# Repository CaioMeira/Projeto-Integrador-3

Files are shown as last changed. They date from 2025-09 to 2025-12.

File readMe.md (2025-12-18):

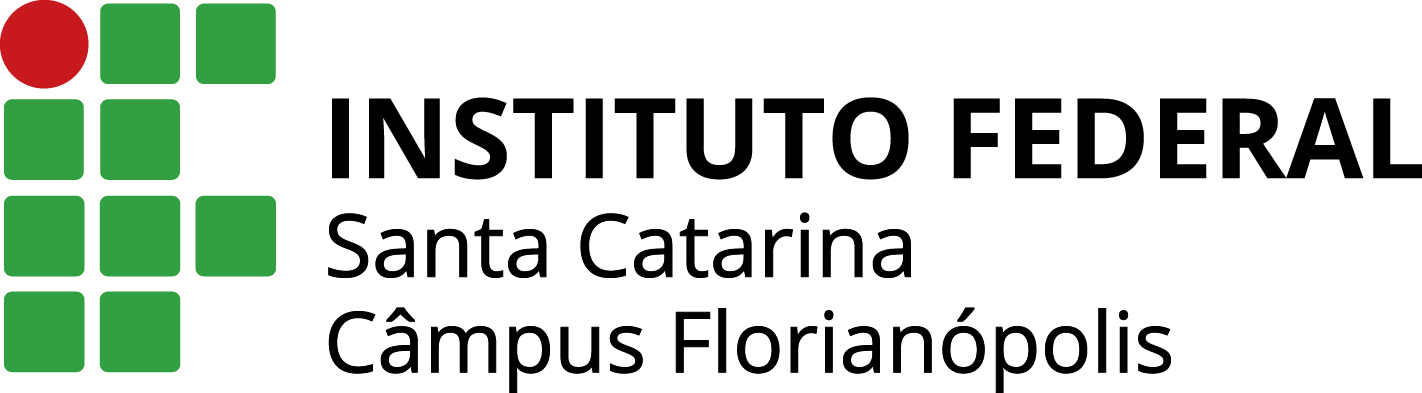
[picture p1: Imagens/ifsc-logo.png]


# Projeto Integrador III - Braço Robótico

## Descrição do Projeto

Repositório destinado ao desenvolvimento do **Projeto Integrador III** do curso de Engenharia Eletrônica.  
O projeto consiste na construção de um **braço robótico controlado por ESP32** integrando o protocolo de comunicação **ROS 2**

---

## Requisitos para Executar o Projeto

### 1. Firmware ESP32 (Obrigatório)

**Arduino IDE** com as seguintes bibliotecas instaladas:

- `ESP32Servo` - Controle de servos
- `EEPROM` (incluída no core ESP32)
- `micro_ros_arduino` v2.0.7-humble - Comunicação ROS 2 (opcional)

**Como instalar:**

```
Arduino IDE → Sketch → Include Library → Manage Libraries
Buscar e instalar cada biblioteca acima
```

### 2. Integração ROS 2 (Opcional - 2 métodos)

#### **Método A: Script Python (Recomendado - Funciona com ESP32 padrão)**

- **Python 3.8+**
- **ROS 2 Humble** (Ubuntu 22.04 ou WSL2)
- **pyserial**: `pip3 install pyserial`

**Vantagens:** Não requer modificação no ESP32, funciona com qualquer modelo

#### **Método B: ROS Nativo via micro-ROS Agent (Docker)**

- **Docker** instalado
- **ROS 2 Humble** (Ubuntu 22.04 ou WSL2)
- **ESP32 com biblioteca micro-ROS** compilada no firmware

**Limitação:** ESP32 padrão (520KB RAM) suporta apenas `/run_macro`. Para todos os tópicos, use ESP32-WROVER ou **Método A (Script Python)**.

### 3. Hardware

- ESP32 DevKit (qualquer modelo)
- 6× Servos MG996R ou similar
- Fonte 5V/6V 3A

---

> ## Equipe
>
> - Caio Neves Meira
> - Guilherme da Costa Franco
> - Marcelo Zampieri Pereira da Silva
>
> Professores: Matheus Leitzke Pinto e Renan Augusto Starke

---

<p align=center><strong>SUMÁRIO</strong></p>

[**1. INTRODUÇÃO**](./introdução.md)<br>
[**2. COMPONENTES**](./componentes.md)<br>
[**3. LISTA DE COMPONENTES**](./lista-de-componentes.md)<br>
[**4. IMAGENS**](./Imagens/)<br>

---

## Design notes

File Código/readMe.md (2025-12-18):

# Braço Robótico ESP32

Este projeto implementa o controle e a automação de um braço robótico de **5 graus de liberdade**, utilizando um **ESP32**.

O foco desta versão foi a **reestruturação modular** e a adoção de uma **arquitetura não-bloqueante baseada em Máquinas de Estado**, garantindo **movimentos suaves (smooth move)** e execução de **rotinas complexas (macros)**.

## Integração ROS 2

Este firmware suporta **integração com ROS 2 Humble** através de duas abordagens:

### Método Recomendado: Bridge Python (`ros2serial_bridge.py`)

- **Funciona com qualquer ESP32** (incluindo modelos padrão sem PSRAM)
- **Todos os tópicos ROS** disponíveis: `/run_macro`, `/run_pose`, `/joint_goals`
- **Setup simples:** `pip install pyserial` + `python3 ros2serial_bridge.py /dev/ttyUSB0`
- **Estabilidade garantida:** Sem limitações de RAM

**Documentação completa:** [IntegraçãoROS.md](./IntegraçãoROS.md)

### Alternativa: micro-ROS Nativo

- Requer ESP32-WROVER (com PSRAM) para todos os tópicos
- ESP32 padrão suporta apenas `/run_macro` (limitação de RAM)
- Latência mais baixa (~10ms vs ~50ms)

**Recomendação:** Use o **Bridge Python** para desenvolvimento e testes. É mais simples e funciona em qualquer hardware!

---

## Arquitetura do Firmware (Modularização)

O código foi dividido em **módulos (namespaces)** com responsabilidades bem definidas, facilitando a leitura, o teste e a expansão.

| **Módulo (Namespace)** | **Responsabilidade Principal** | **Descrição Detalhada** |
| --- | --- | --- |
| **Config** | Constantes e Estruturas | Define pinos, tamanhos de arrays, constantes de velocidade, endereços de EEPROM e structs de dados (`Pose`, `Macro`, `StoredData`). |
| **MotionController** | Movimento dos Servos (Físico)  | Executa o movimento suave (interpolação) dos servos no tempo. Contém variáveis globais de posição, limites e offsets. |
| **Calibration** | Limites e Offsets | Gerencia comandos de `min`, `max`, `offset` e `align` para calibração de software e hardware. |
| **Storage** | Persistência (EEPROM) | Salva e carrega o estado de calibração (min/max/offsets) e a última posição. |
| **PoseManager** | Poses Estáticas | Gerencia criação, listagem, carregamento e exclusão de **Poses** na EEPROM. |
| **MacroManager** | Rotinas Sequenciais | Gerencia criação, listagem, carregamento e exclusão de **Macros** (sequências de poses e tempos). |
| **Sequencer** | Máquina de Estados (Automação) | Executa Macros de forma não-bloqueante, usando `MotionController::isMoving()` para avançar entre passos. |
| **CommandParser** | Interface Serial | Interpreta comandos de texto da Serial (`move`, `set`, `pose save`, `macro play`, etc.) e roteia ao módulo correto. |
| **robotic_arm.ino** | Ponto de Entrada | Inicializa Serial, EEPROM, chama `setup()` dos módulos e mantém o loop principal não-bloqueante. |

---

## Principais Funcionalidades

### 1. Movimento Suave e Não-Bloqueante

**Módulos:** `MotionController` & `robotic_arm.ino`

- **Interpolação (Smooth Move):**  
  O movimento entre A → B é dividido em pequenos passos.  
  O `MotionController::update()` é chamado continuamente no `loop()` principal, calculando ângulos com a função de easing `EaseInOutQuad`.

- **Não-Bloqueante:**  
  O `loop()` principal continua executando outras tarefas (como ler a Serial e atualizar o Sequencer) pois o controle é baseado em `millis()` e não em `delay()`.

#### 1.1 Easing (Interpolação Suave)

Para garantir que o braço **não comece nem pare de forma abrupta** (“engasgos”), utilizamos uma técnica chamada **Easing (abrandamento)**.

Em vez de um movimento **linear** (velocidade constante), o código implementa a equação **EaseInOutQuad**:

$$
\text{easeProgress} =
\begin{cases}
2 \times \text{progress}^2, & \text{se } \text{progress} < 0.5 \\
1 - \dfrac{(-2 \times \text{progress} + 2)^2}{2}, & \text{se } \text{progress} \geq 0.5
\end{cases}
$$

- `progress` → progresso linear (tempo) de `0.0` a `1.0`
- `easeProgress` → progresso ajustado, também de `0.0` a `1.0`

#### 1.2 Efeito da equação

| Etapa | Descrição |
| --- | --- |
| **Início Suave** | O braço começa a se mover lentamente. |
| **Aceleração Central** | A velocidade aumenta gradualmente no meio do trajeto. |
| **Fim Suave** | A velocidade diminui gradualmente ao se aproximar da posição alvo. |

> [!Note]
> Este método de interpolação não apenas torna os movimentos visualmente mais naturais e robóticos, mas também reduz o estresse mecânico e o ruído dos servos.

---

### 2 Módulos de Persistência (EEPROM/Flash)

Para manter o estado do braço robótico, incluindo calibrações, a última posição e as rotinas programadas, o sistema utiliza a memória não-volátil EEPROM (ou a emulação de EEPROM em Flash no caso do ESP32). A memória é organizada em três seções lógicas:

---

#### 2.1. Módulo Storage (Configurações do Sistema)

Este é o módulo base (`Storage.cpp`), responsável por salvar e carregar os dados essenciais para o funcionamento inicial do braço.

**O que Salva:**

- A última posição lógica conhecida de cada servo (`currentAngles`).
- Os limites de software (`minAngles`, `maxAngles`) definidos para segurança.
- Os offsets de calibração (`offsets`) para corrigir desvios mecânicos dos servos.

**Funcionalidade:**  
O módulo utiliza uma chave mágica (`EEPROM_MAGIC`) para garantir que os dados lidos sejam válidos.  
Ao carregar o estado, ele pode opcionalmente iniciar um movimento suave para a última posição salva (como é feito no `setup()` principal).

**Comandos:** `save` e `load`.

---

#### 2.2. Módulo PoseManager (Poses Estáticas)

O `PoseManager` (`PoseManager.cpp`) permite que o usuário defina e armazene posições-chave (poses) na EEPROM para serem reutilizadas.

**Estrutura:**  
As poses são armazenadas em slots de memória fixos (definidos por `MAX_POSES`, atualmente 10), cada uma contendo um nome curto e os ângulos de todos os servos.

**Integração com Movimento:**  
O comando de carregamento de pose (`loadPoseByName`) é diretamente integrado ao `MotionController`, iniciando um movimento suave com a interpolação **EaseInOutQuad** (explicada acima) na duração especificada ou calculada.

**Comandos:**  
`savepose <nome>`, `loadpose <nome> [tempo]`, `listpose` e `delpose <nome>`.

---

#### 2.3. Módulo MacroManager e Sequencer (Rotinas Programadas)

Estes módulos trabalham em conjunto para permitir a criação e execução de sequências complexas de movimento.

**MacroManager:**  
Responsável pela persistência e gestão de **Macros** (`MacroManager.cpp`), que são listas de passos.  
Cada passo (`MacroStep`) armazena o nome de uma Pose e um tempo de espera (`delay_ms`).

**Sequencer:**  
É a **Máquina de Estados (FSM)** que executa a macro de forma não-bloqueante (`Sequencer.cpp`).  
O seu `update()` alterna entre os estados:

- **MOVING:** Enquanto o `MotionController` interpola para a próxima pose.
- **WAITING:** Esperando o `delay_ms` do passo atual antes de avançar.
- **IDLE:** Quando não há macro em execução.

**Comandos:**  
`macro create <nome>`, `macro add <pose> <tempo>`, `macro save <nome>`, `macro play <nome>`, `macro stop`, `macro list` e `macro delete <nome>`.

---

## 3. Tabela de Melhorias (Código Legado vs. Modular)

| **Funcionalidade** | **Código Legado (Monolítico)** | **Versão Modular v5.0** |
| --- | --- | --- |
| **Arquitetura** | Código único (legacy.ino). Configurações, lógica e parsing misturados. | Modular: Namespaces dedicados (MotionController, Storage, etc.) com alto reuso. |
| **Qualidade do Movimento** | Interpolação linear simples, movimentos bruscos. | Interpolação Suave com `EaseInOutQuad`. |
| **Execução de Macros** | Misturado ao parser, sem Máquina de Estados. | Máquina de Estados Não-Bloqueante (`Sequencer`). |
| **Calibração/Persistência** | Misturada à lógica de parsing. | Módulos dedicados `Calibration` e `Storage`. |
| **Comunicação (Parsing)** | `if/else` extensos no `loop()`. | Delegador de Comandos (`CommandParser`). |
| **Manutenção/Escalabilidade** | Baixa: alterações afetam todo o sistema. | Alta: novos recursos exigem apenas 1–2 módulos. |

---

## 4. Comandos de Serial (Resumo)

| **Categoria**  | **Comando** | **Exemplo** | **Descrição** |
| --- | --- | --- | --- |
| **Movimento**  | `move <s0> ... <s6> [tempo]` | `move 90 90 90 90 90 90 90 1000` | Move todos os servos em tempo ms. |
| **Ajuste** | `set <idx> <ang> [tempo]` | `set 3 120 500` | Move o servo 3 para 120° em 500ms. |
| **Poses** | `pose save <nome>` | `pose save HOME` | Salva a posição atual. |
| | `pose load <nome> [tempo]` | `pose load HOME 2000` | Carrega uma pose. |
| **Macros** | `macro create <nome>` | `macro create ROTINA1` | Inicia a criação de uma macro. |
| | `macro add <nome> <pose> <delay>` | `macro add ROTINA1 P1 500` | Adiciona um passo à macro. |
| | `macro play <nome>` | `macro play ROTINA1` | Executa macro de forma não-bloqueante. |
| | `macro stop` | `macro stop` | Interrompe a execução atual. |
| **Calibração** | `offset <idx> <valor>` | `offset 1 -5` | Define offset de calibração. |
| | `min <idx> <ang>` | `min 3 20` | Define o limite mínimo. |
| **Sistema** | `status` | `status` | Exibe posição, limites e offsets. |
| | `save` | `save` | Salva calibração e última posição. |
| | `load` | `load` | Carrega calibração e última posição. |
| | `help` | `help` | Exibe o menu de comandos. |

---

## 5. Integração com ROS 2 (micro-ROS)

O firmware do braço robótico possui um **módulo ROS** (`RosInterface`) que transforma o ESP32 em um **nó ROS 2** nativo, permitindo integração completa com o ecossistema ROS (RViz2, MoveIt2, scripts Python/C++).

### 5.1. Como Funciona

**Arquitetura:**

```
PC (Ubuntu) ←───────────────── USB/Serial ──────────────→ ESP32 (micro-ROS)
    ↓                                                            ↓
Agent (Docker/Script .py)                                 robotic_arm_node
    ↓                                                            ↓
ROS 2 Humble                                           Publishers/Subscribers
```

**Componentes:**

- **ESP32:** Roda o nó `robotic_arm_node` com micro-ROS via Serial (115200 baud)
- **PC:** Executa o micro-ROS Agent (Docker) que faz a ponte Serial ↔ ROS 2
- **Comunicação:** Bidirecional - o braço publica seu estado e recebe comandos

**Integração com Módulos Existentes:**

- `RosInterface` utiliza `MotionController`, `PoseManager` e `Sequencer`
- Todos os comandos Serial continuam funcionando normalmente
- O modo ROS é **não-bloqueante** e coexiste com o parsing Serial

---

### 5.2. Tópicos ROS (Publishers)

O braço **publica** seu estado a **10 Hz**:

| **Tópico** | **Tipo** | **Conteúdo** | **Exemplo de Saída** |
| --- | --- | --- | --- |
| `/joint_states` | `sensor_msgs/JointState` | Posição atual de todas as juntas (em **radianos**) | `position: [1.57, 2.27, 2.27, 1.75, 1.22, 2.09, 1.75]` |
| `/arm_status` | `std_msgs/String` | Estado do braço | `"IDLE"` / `"MOVING"` / `"RUNNING_MACRO"` |

**Monitorar no terminal:**

```bash
# Ver estado das juntas em tempo real
ros2 topic echo /joint_states

# Ver status do braço
ros2 topic echo /arm_status
```

**Conversão:** Os ângulos são publicados em **radianos** (padrão ROS):

- 0° = 0 rad | 90° = 1.57 rad | 180° = 3.14 rad

---

### 5.3. Tópicos ROS (Subscribers)

O braço **escuta** comandos via 3 tópicos:

| **Tópico** | **Tipo** | **Descrição** | **Exemplo de Uso** |
| --- | --- | --- | --- |
| `/joint_goals` | `sensor_msgs/JointState` | Comandar ângulos específicos (radianos) | Mover servo 0 para 90° (1.57 rad) |
| `/run_pose` | `std_msgs/String` | Executar pose salva pelo nome | Carregar pose `"HOME"` |
| `/run_macro` | `std_msgs/String` | Executar macro pelo nome | Executar sequência `"ROTINA1"` |

#### Exemplos de Comandos:

**1. Mover todos os servos para 90°:**

```bash
ros2 topic pub /joint_goals sensor_msgs/msg/JointState "{
  name: ['junta_base', 'junta_ombro1', 'junta_ombro2', 'junta_cotovelo', 'junta_mao', 'junta_pulso', 'junta_garra'],
  position: [1.57, 1.57, 1.57, 1.57, 1.57, 1.57, 1.57]
}" --once
```

**2. Executar pose salva:**

```bash
ros2 topic pub /run_pose std_msgs/msg/String "data: 'HOME'" --once
```

**3. Executar macro:**

```bash
ros2 topic pub /run_macro std_msgs/msg/String "data: 'ROTINA1'" --once
```

---

### 5.4. Configuração Rápida

#### Passo 1: Compilar e Enviar o Firmware

1. Instale a biblioteca `micro_ros_arduino` no Arduino IDE
2. Compile e envie o código para o ESP32
3. O ESP32 aguardará a conexão do Agent

#### Passo 2: Rodar o Agent no PC

```bash
# Identificar porta USB (geralmente /dev/ttyUSB0 ou /dev/ttyACM0)
dmesg | grep tty

# Executar Agent via Docker
docker run -it --rm --privileged \
    -v /dev:/dev \
    microros/micro-ros-agent:humble \
    serial --dev /dev/ttyUSB0 -b 115200
```

**Saída Esperada:**

```
[INFO] Serial device: /dev/ttyUSB0, baudrate: 115200
[INFO] session established
```

#### Passo 3: Verificar Conexão

```bash
# Listar tópicos disponíveis
ros2 topic list

# Deve aparecer:
# /arm_status
# /joint_goals
# /joint_states
# /run_macro
# /run_pose
```

---

### 5.5. Saídas Esperadas e Diagnóstico

**Conexão Bem-Sucedida:**

**No Serial Monitor do ESP32:**

```
Iniciando RosInterface (modo SERIAL)...
Transporte micro-ROS: Serial (USB)
micro-ROS (Serial) configurado e pronto.
```

**No terminal do Agent:**

```
[1669123457.123] session established
[1669123457.124] Root.cpp init_session
```

**Testando comunicação:**

```bash
# Publicar estado deve atualizar em tempo real
ros2 topic hz /joint_states
# Saída: average rate: 10.000

# Status deve responder ao movimento
ros2 topic echo /arm_status
# "IDLE" quando parado, "MOVING" durante movimento
```

---

**Problemas Comuns:**

| **Sintoma** | **Causa Provável** | **Solução** |
| --- | --- | --- |
| Agent não conecta | Permissões USB | `sudo usermod -aG dialout $USER` e fazer logout/login  |
| Tópicos não aparecem | Agent não está rodando | Verificar `docker ps` |
| ESP32 reseta sozinho | Watchdog timeout | Verificar se `RosInterface::update()` está no `loop()` |
| Erro "X posições recebidas" | Número incorreto de juntas | Sempre enviar 7 valores em `/joint_goals` |

---

**Documentação Completa:**  
Para detalhes avançados, troubleshooting e exemplos de integração com MoveIt2/RViz2, consulte o arquivo [`IntegraçãoROS.md`](./IntegraçãoROS.md).

---

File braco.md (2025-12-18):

# Impressão 3D do Braço Robótico

Este projeto iniciou-se com a utilização de um **braço robótico parcialmente montado**, que desde as primeiras etapas apresentou **limitações estruturais e funcionais relevantes**. O modelo inicial possuía **5 graus de liberdade (DOF)** e era acionado por **7 servomotores**.

Com o avanço do desenvolvimento do código e a realização de testes experimentais, constatou-se que essas limitações físicas **comprometiam a confiabilidade do sistema**, além de dificultarem a evolução segura e consistente do projeto.

Diante desse cenário — e considerando a **experiência limitada da equipe no desenvolvimento e modelagem de componentes 3D** — optou-se pela **substituição do braço original** por um modelo já consolidado e amplamente utilizado em projetos públicos.

O novo braço robótico selecionado também possui **5 DOF**, porém utiliza **6 servomotores**, apresentando uma **arquitetura mecânica mais simples, robusta e confiável**, alinhada aos requisitos técnicos e aos objetivos do projeto.

A partir dos arquivos `.stl` disponibilizados pelo projeto escolhido, todas as peças foram impressas utilizando as **quatro impressoras 3D disponíveis no laboratório LPAE** e o software UltiMaker Cura, resultando em uma estrutura física **mais estável, precisa e adequada** para a continuidade do projeto.

---

## Visualização dos Modelos

Os modelos 3D utilizados na construção do novo braço robótico estão disponíveis no formato `.stl` e podem ser acessados diretamente no diretório abaixo:

**Diretório dos modelos 3D**  
https://github.com/CaioMeira/Projeto-Integrador-3/tree/main/Imagens/3D

---

##  Componentes do Braço Robótico

O novo braço robótico é composto por **10 modelos distintos**, totalizando a impressão de **14 peças**, conforme descrito na tabela a seguir:

| Arquivo `.stl` | Quantidade | Função |
|---|:---:|---|
| `Arm01.stl` | 1 | Segmento principal do braço |
| `Arm 02 v3.stl` | 1 | Segundo segmento articulado |
| `Arm 03.stl` | 1 | Terceiro segmento do braço |
| `Base.stl` | 1 | Base estrutural do braço robótico |
| `Waist.stl` | 1 | Estrutura de rotação do eixo principal |
| `gear1.stl` | 1 | Engrenagem garra |
| `gear2.stl` | 1 | Engrenagem garra |
| `Gripper base.stl` | 1 | Base do mecanismo da garra |
| `Gripper 1.stl` | 2 | Garras de preensão |
| `grip link 1.stl`  | 4 | Elos do mecanismo da garra |

**Total de peças impressas:** **14 unidades**

 O conjunto dessas peças resulta em um **braço robótico completo, funcional e mecanicamente estável**.

---

##  Tecnologias Utilizadas

- Impressão 3D (arquivos `.stl`)
- Servomotores
- Modelos mecânicos open-source
- Infraestrutura do laboratório **LPAE**

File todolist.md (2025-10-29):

### Próximos passos a serem executados no projeto.

- [ ] Corrigir conexão mecânica entre servomotor 1 e servomotor 3

- [X] Desenvolver sistema de alimentação para prover o necessário de energia para um uso síncrono dos servomotores
  
- [ ] Devido Cable Management para evitar problemas durante o movimento

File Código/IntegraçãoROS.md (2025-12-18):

# Guia de Integração micro-ROS com ESP32

**Versão:** 1.0  
**ROS 2:** Humble  
**Plataforma:** ESP32 + Ubuntu 22.04  
**Protocolo:** Serial (USB)

---

## Índice

1. [Visão Geral](#visão-geral)
2. [Arquitetura](#arquitetura)
3. [Configuração do ESP32](#passo-1-configuração-do-esp32)
4. [Agente micro-ROS no PC](#passo-2-agente-micro-ros-no-pc)
5. [Testando a Comunicação](#passo-3-testando-a-comunicação)
6. [Comandos Disponíveis](#comandos-ros-disponíveis)
7. [Troubleshooting](#troubleshooting)

---

## Visão Geral

Seu braço robótico agora é um **nó ROS 2** (`robotic_arm_node`) que:

- **Publica** estado das juntas e status do braço (10 Hz)
- **Recebe** comandos de movimento, poses e macros via ROS
- Comunica via **Serial (USB)** com micro-ROS Agent no PC
- Compatível com **ROS 2 Humble** (Ubuntu 22.04)

### Por que usar micro-ROS?

- Integração nativa com ecossistema ROS 2
- Visualização no RViz2 (com URDF do braço)
- Compatibilidade com MoveIt2 para planejamento de trajetórias
- Scripts Python/C++ para automação complexa

---

## Arquitetura

```
┌─────────────────────────────────────────────────────────────┐
│                       PC Linux (Ubuntu 22.04)               │
│  ┌──────────────────────────────────────────────────────┐   │
│  │  micro-ROS Agent (Docker)                            │   │
│  │  - Porta: /dev/ttyUSB0 (Serial)                      │   │
│  │  - Baudrate: 115200                                  │   │
│  └─────────────────┬────────────────────────────────────┘   │
│                    │ USB                                    │
│  ┌─────────────────┴────────────────────────────────────┐   │
│  │  ROS 2 Humble                                        │   │
│  │  - ros2 topic list/echo/pub                          │   │
│  │  - RViz2, MoveIt2, etc                               │   │
│  └──────────────────────────────────────────────────────┘   │
└─────────────────────────────────────────────────────────────┘
                          ▲
                          │ Serial (115200 baud)
                          ▼
┌─────────────────────────────────────────────────────────────┐
│                       ESP32 (Braço Robótico)                │
│  ┌──────────────────────────────────────────────────────┐   │
│  │  robotic_arm_node (micro-ROS)                        │   │
│  │                                                      │   │
│  │  Publishers (10 Hz):                                 │   │
│  │    - /joint_states → Ângulos atuais (radianos)       │   │
│  │    - /arm_status → IDLE / MOVING / RUNNING_MACRO     │   │
│  │                                                      │   │
│  │  Subscribers:                                        │   │
│  │    - /joint_goals ← Comandar ângulos (radianos)      │   │
│  │    - /run_pose ← Executar pose salva                 │   │
│  │    - /run_macro ← Executar macro (sequência)         │   │
│  └──────────────────────────────────────────────────────┘   │
│  ┌──────────────────────────────────────────────────────┐   │
│  │  MotionController + PoseManager + Sequencer          │   │
│  │  (Código otimizado Fases 1 e 2)                      │   │
│  └──────────────────────────────────────────────────────┘   │
└─────────────────────────────────────────────────────────────┘
```

### Fluxo de Comunicação

1. **ESP32** aguarda conexão do Agent via Serial
2. **PC** executa micro-ROS Agent (Docker) conectado à porta USB
3. **Agent** estabelece comunicação bidirecional
4. **ROS 2** vê o ESP32 como um nó normal (`robotic_arm_node`)
5. Você pode usar `ros2 topic pub/echo` normalmente!

---

## Passo 1: Configuração do ESP32

### 1.1 Instalar Biblioteca micro-ROS

**Arduino IDE:**

```
Sketch → Include Library → Manage Libraries
Buscar: "micro_ros_arduino"
Instalar versão compatível com ROS 2 Humble
```

**PlatformIO:**

```ini
[env:esp32]
platform = espressif32
board = esp32dev
framework = arduino
lib_deps =
    https://github.com/micro-ROS/micro_ros_arduino/releases/download/v2.0.7/micro_ros_arduino-2.0.7.zip
```

### 1.2 Compilar e Enviar

1. Abra o projeto em `Código/robotic_arm/`
2. Compile e envie para o ESP32
3. Abra o **Monitor Serial** (115200 baud)

### 1.3 Verificar Inicialização

Você deve ver:

```
Iniciando Sistema do Braco Robotico v5.0...
Watchdog Timer configurado (15s).
...
Iniciando RosInterface (modo SERIAL)...
Transporte micro-ROS: Serial (USB)
micro-ROS (Serial) configurado e pronto.
```

> **Atenção:** O ESP32 ficará **esperando** o Agent se conectar. Isso é normal!

---

## Passo 2: Agente micro-ROS no PC

### 2.1 Identificar a Porta Serial

Conecte o ESP32 ao PC via USB e execute:

```bash
dmesg | grep tty
```

**Saída esperada:**

```
[12345.678] usb 1-1: FTDI USB Serial Device converter now attached to ttyUSB0
```

A porta é `/dev/ttyUSB0` (ou `ttyACM0`, depende do ESP32).

### 2.2 Rodar o Agent (Docker)

**Método 1: Acesso privilegiado (mais simples)**

```bash
docker run -it --rm --privileged \
    -v /dev:/dev \
    microros/micro-ros-agent:humble \
    serial --dev /dev/ttyUSB0 -b 115200
```

**Método 2: Mapear dispositivo específico (mais seguro)**

```bash
docker run -it --rm \
    --device=/dev/ttyUSB0:/dev/ttyUSB0 \
    microros/micro-ros-agent:humble \
    serial --dev /dev/ttyUSB0 -b 115200
```

### 2.3 Verificar Conexão

**Saída esperada no Agent:**

```
[1669123456.789] micro-ROS Agent
[1669123456.790] Version: 2.0.0
[1669123456.791] Serial device: /dev/ttyUSB0, baudrate: 115200
[1669123457.123] session established
[1669123457.124] Root.cpp init_session
```

> **Sucesso!** O ESP32 agora está conectado ao ROS 2.

---

## Passo 3: Testando a Comunicação

** IMPORTANTE:** Mantenha o terminal do Agent **rodando** durante todos os testes!

### 3.1 Listar Tópicos Disponíveis

Abra um **novo terminal** e execute:

```bash
ros2 topic list
```

**Saída esperada:**

```
/arm_status
/joint_goals
/joint_states
/parameter_events
/rosout
/run_macro
/run_pose
```

> Se você vê `/joint_states` e `/arm_status`, está funcionando!

---

### 3.2 Monitorar o Estado do Braço (Publishers)

#### Ver Estado das Juntas (10 Hz)

```bash
ros2 topic echo /joint_states
```

**Saída (exemplo):**

```yaml
header:
  stamp:
    sec: 1234567890
    nanosec: 123456789
  frame_id: ""
name:
  - junta_base
  - junta_ombro1
  - junta_ombro2
  - junta_cotovelo
  - junta_mao
  - junta_pulso
  - junta_garra
position:
  - 1.5707963 # 90° em radianos
  - 2.2689280 # 130° em radianos
  - 2.2689280 # 130° em radianos
  - 1.7453292 # 100° em radianos
  - 1.2217304 # 70° em radianos
  - 2.0943951 # 120° em radianos
  - 1.7453292 # 100° em radianos
velocity: []
effort: []
```

> **Dica:** Para converter radianos → graus: `graus = radianos × 180 / π`

#### Ver Status do Braço

```bash
ros2 topic echo /arm_status
```

**Saída:**

```yaml
data: "IDLE"
```

Possíveis valores:

- `IDLE` - Braço parado
- `MOVING` - Executando movimento suave
- `RUNNING_MACRO` - Executando sequência de macro

---

### 3.3 Comandar o Braço (Subscribers)

#### Comando 1: Executar Pose Salva

> **Pré-requisito:** Você deve ter uma pose salva (via Serial: `SAVE home`).

```bash
ros2 topic pub /run_pose std_msgs/msg/String "data: 'home'" --once
```

O braço deve se mover para a pose `home`.

---

#### Comando 2: Comandar Ângulos Específicos

Mover todos os servos para **90 graus** (1.5708 radianos):

```bash
ros2 topic pub /joint_goals sensor_msgs/msg/JointState "{
  name: ['junta_base', 'junta_ombro1', 'junta_ombro2', 'junta_cotovelo', 'junta_mao', 'junta_pulso', 'junta_garra'],
  position: [1.57, 1.57, 1.57, 1.57, 1.57, 1.57, 1.57]
}" --once
```

**Conversão rápida:**

- 0° = 0 rad
- 45° = 0.785 rad
- 90° = 1.57 rad
- 135° = 2.356 rad
- 180° = 3.14 rad

---

#### Comando 3: Executar Macro

**Pré-requisito:** Você deve ter uma macro salva (via Serial).

**Exemplo de criação de macro via Serial:**

```
RECORD pegar
MOVE 0 45
WAIT 1000
MOVE 1 90
END
```

**Executar via ROS:**

```bash
ros2 topic pub /run_macro std_msgs/msg/String "data: 'pegar'" --once
```

O braço executa toda a sequência automaticamente.

---

## Comandos ROS Disponíveis

### Subscribers (Enviar Comandos)

| Tópico | Tipo | Descrição | Exemplo |
| --- | --- | --- | --- |
| `/joint_goals` | `sensor_msgs/JointState` | Comandar ângulos em **radianos** | Ver [Comando 2](#comando-2-comandar-ângulos-específicos) |
| `/run_pose` | `std_msgs/String` | Executar pose salva pelo nome | `data: 'home'` |
| `/run_macro` | `std_msgs/String` | Executar macro pelo nome | `data: 'pegar'` |

### Publishers (Receber Feedback)

| Tópico | Tipo | Frequência | Descrição |
| --- | --- | --- | --- |
| `/joint_states` | `sensor_msgs/JointState` | 10 Hz | Posição atual de todas as juntas |
| `/arm_status` | `std_msgs/String` | 10 Hz | Status: `IDLE`, `MOVING`, `RUNNING_MACRO` |

---

---

## ✅ Alternativa: Bridge Python (Recomendado)

### Por que usar o Script Python?

**Devido a limitações de memória do ESP32 padrão (520KB RAM)**, a integração micro-ROS nativa suporta apenas o tópico `/run_macro`. Para habilitar **todos os tópicos ROS** sem modificar hardware:

✅ **Use o script `ros2serial_bridge.py`** - Funciona com qualquer ESP32!

Este script atua como um **tradutor** entre ROS 2 e comandos seriais do ESP32, eliminando a necessidade de processar ROS diretamente no microcontrolador.

### Arquitetura do Bridge

```
┌──────────────────────────────────────────┐
│       PC Linux (ROS 2 Humble)            │
│                                          │
│  ┌────────────────────────────────────┐  │
│  │  ros2serial_bridge.py              │  │
│  │  • Subscribers: /run_macro,        │  │
│  │    /run_pose, /joint_goals         │  │
│  │  • Publishers: /joint_states,      │  │
│  │    /arm_status                     │  │
│  │  • Conversão: ROS ↔ Serial         │  │
│  └────────────┬───────────────────────┘  │
│               │ Serial (pyserial)        │
└───────────────┼──────────────────────────┘
                │ USB
                ▼
┌──────────────────────────────────────────┐
│       ESP32 (Firmware Padrão)            │
│  • Recebe comandos via Serial            │
│  • Executa movimentos                    │
│  • Responde status                       │
└──────────────────────────────────────────┘
```

### Instalação do Bridge Python

#### 1. Instalar Dependências

```bash
# ROS 2 Humble (se ainda não tiver)
sudo apt install ros-humble-desktop

# pyserial
pip3 install pyserial
```

#### 2. Verificar Porta Serial

```bash
# Conecte o ESP32 via USB
ls /dev/ttyUSB*
# ou
ls /dev/ttyACM*
```

#### 3. Dar Permissões de Acesso

```bash
sudo usermod -aG dialout $USER
# Fazer logout e login novamente
```

### Uso do Bridge Python

#### Iniciar o Bridge

```bash
# Source ROS 2
source /opt/ros/humble/setup.bash

# Executar bridge (substitua /dev/ttyUSB0 pela sua porta)
python3 ros2serial_bridge.py /dev/ttyUSB0
```

**Saída esperada:**

```
[INFO] [robotic_arm_bridge]: Conectando a /dev/ttyUSB0 @ 115200...
[INFO] [robotic_arm_bridge]: Conexão serial estabelecida!
[INFO] [robotic_arm_bridge]: Bridge ROS 2 ↔ Serial inicializado!
[INFO] [robotic_arm_bridge]: Tópicos ativos:
[INFO] [robotic_arm_bridge]:   SUB: /run_macro, /run_pose, /joint_goals
[INFO] [robotic_arm_bridge]:   PUB: /joint_states, /arm_status
```

---

### Testando com o Bridge Python

#### Listar Tópicos

```bash
# Abra um NOVO terminal
source /opt/ros/humble/setup.bash
ros2 topic list
```

**Saída esperada:**

```
/arm_status       ✅
/joint_goals      ✅ (via bridge)
/joint_states     ✅
/run_macro        ✅ (via bridge)
/run_pose         ✅ (via bridge)
```

#### Comandar Ângulos Específicos

```bash
ros2 topic pub /joint_goals sensor_msgs/msg/JointState "{
  name: ['base','ombro1','ombro2','cotovelo','mao','pulso','garra'],
  position: [1.57, 1.57, 1.57, 1.57, 1.57, 1.57, 1.57]
}" --once
```

**O que acontece:**

1. Bridge recebe mensagem ROS em `/joint_goals`
2. Converte radianos → graus: `[90, 90, 90, 90, 90, 90, 90]`
3. Envia comando serial: `move 90 90 90 90 90 90 90`
4. ESP32 executa movimento
5. Bridge publica feedback em `/arm_status`: `MOVING` → `IDLE`

#### Executar Pose

```bash
ros2 topic pub /run_pose std_msgs/msg/String "data: 'pose1'" --once
```

**Tradução pelo bridge:** `pose load pose1`

#### Executar Macro

```bash
ros2 topic pub /run_macro std_msgs/msg/String "data: 'ida'" --once
```

**Tradução pelo bridge:** `macro play ida`

---

### Comparação: Bridge Python vs micro-ROS Nativo

| Aspecto | Bridge Python | micro-ROS Nativo |
| --- | --- | --- |
| **Requisitos ESP32** | Firmware padrão | micro-ROS compilado |
| **RAM necessária** | Qualquer modelo | ESP32-WROVER (PSRAM) |
| **Tópicos suportados** | ✅ Todos (3 subs + 2 pubs) | ⚠️ Apenas /run_macro (ESP32 padrão) |
| **Instalação** | `pip install pyserial` | Docker + Agent |
| **Latência** | ~50-100ms | ~10-20ms |
| **Complexidade** | 🟢 Baixa | 🔴 Alta |
| **Estabilidade** | ✅ Alta | ⚠️ Reset loops (ESP32 padrão) |
| **Recomendado para** | Desenvolvimento/Produção | Sistemas com PSRAM |

### Quando Usar Cada Método?

#### Use o **Bridge Python** se:

- ✅ Você tem ESP32 **padrão** (sem PSRAM)
- ✅ Quer **todos os tópicos** ROS funcionando
- ✅ Prefere **simplicidade** de setup
- ✅ Latência de ~50ms é aceitável
- ✅ Está em fase de **desenvolvimento/testes**

#### Use o **micro-ROS Nativo** se:

- ⚠️ Você tem ESP32-**WROVER** (com PSRAM)
- ⚠️ Precisa de **latência mínima** (<20ms)
- ⚠️ Quer eliminar o PC intermediário
- ⚠️ Está disposto a lidar com **limitações de RAM**

---

## Troubleshooting

### Problema 1: Agent não conecta (micro-ROS Nativo)

**Sintomas:**

```
[ERROR] Cannot open serial device /dev/ttyUSB0
```

**Solução:**

```bash
# Verificar permissões
ls -l /dev/ttyUSB0

# Adicionar seu usuário ao grupo dialout
sudo usermod -aG dialout $USER

# Fazer logout e login novamente
```

---

### Problema 2: ESP32 não aparece no `ros2 topic list`

**Verificar:**

1. Agent está rodando? (Docker container ativo?)
2. ESP32 mostra "session established" no Serial Monitor?
3. Baudrate correto? (115200 em ambos os lados)

**Teste:**

```bash
# Reiniciar ESP32
# Pressione o botão RST no ESP32

# Verificar Agent
docker ps  # Container deve estar UP
```

---

### Problema 3: "ERRO ROS: /joint_goals recebido com X posições"

**Causa:** Você enviou número incorreto de ângulos.

**Solução:** Sempre envie **7 posições** (uma para cada servo):

```bash
ros2 topic pub /joint_goals sensor_msgs/msg/JointState "{
  name: ['j0','j1','j2','j3','j4','j5','j6'],
  position: [1.57, 1.57, 1.57, 1.57, 1.57, 1.57, 1.57]
}" --once
```

---

### Problema 4: Watchdog reseta o ESP32

**Causa:** Loop principal travou por >15 segundos.

**Verificar:**

- Nenhum `delay()` longo no código
- `RosInterface::update()` está sendo chamado no `loop()`
- Nenhuma operação bloqueante

---

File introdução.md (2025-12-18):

# Projeto Integrador III - Braço Robótico

## Problema  
O Brasil ainda enfrenta grandes desafios relacionados ao desenvolvimento tecnológico e industrial.  
Apesar de possuir abundância de matéria-prima, grande parte dela é exportada para países que, por sua vez, a transformam em produtos de alto valor agregado e posteriormente os revendem ao mercado brasileiro.  

Esse ciclo resulta em uma dependência tecnológica significativa, altos custos para aquisição de equipamentos e máquinas industriais, além de reduzir a competitividade das indústrias nacionais.  

Nesse contexto, a automação e a robótica se apresentam como ferramentas fundamentais para fomentar o crescimento da indústria local. No entanto, a aquisição de sistemas robóticos modernos, como braços manipuladores industriais, ainda é extremamente onerosa para micro e pequenos empreendedores. Esse fator cria uma barreira de entrada para empresas emergentes que poderiam utilizar tais tecnologias para expandir suas capacidades produtivas e explorar novos mercados.  

O desenvolvimento de um protótipo de braço robótico de baixo custo, utilizando plataformas acessíveis de hardware e software livre, como ESP32 e ROS (Robot Operating System), pode contribuir de forma significativa para reduzir esse obstáculo.  
Tal solução poderia permitir que pequenos negócios implementem processos automatizados de forma mais barata, escalável e eficiente, fortalecendo a indústria nacional e, ao mesmo tempo, diminuindo a dependência externa de equipamentos de alto custo.  

---

## Motivação  
O presente projeto tem sua origem no Projeto Integrador II, no qual já foram trabalhados conceitos relacionados à automação de processos utilizando microcontroladores, sensores e atuadores. Durante essa etapa, foi possível identificar o potencial da automação na solução de problemas práticos e no aumento da eficiência de sistemas.  

Com base nessa experiência, no Projeto Integrador III, buscou-se unir os conceitos de automação com a área de robótica, resultando no desenvolvimento de um protótipo de braço robótico articulado com 5 DoF.  
Essa evolução foi motivada pela necessidade de aprofundar os conhecimentos adquiridos e explorar uma área estratégica para o futuro da indústria 4.0, permitindo também uma aplicação mais direta em problemas reais de manufatura e logística.  

Além disso, a escolha pela integração com o ROS e o simulador Gazebo foi motivada pela possibilidade de aproximar o projeto dos padrões utilizados em centros de pesquisa e indústrias avançadas, garantindo que o aprendizado e os resultados obtidos sejam compatíveis com o estado da arte em robótica.  

Dessa forma, o projeto não apenas consolida os conhecimentos adquiridos ao longo do curso, mas também busca gerar impacto social e econômico, tornando a tecnologia mais acessível e fortalecendo a competitividade das pequenas indústrias brasileiras.  

---

## Objetivo Geral  
Desenvolver um braço robótico de baixo custo, controlado por ESP32, integrado ao sistema ROS e ao simulador Gazebo, de forma a oferecer uma solução acessível para fins educacionais, experimentais e de apoio a micro e pequenos empreendedores.  

---

## Objetivos Específicos  
1. Projetar a arquitetura de hardware e software do braço robótico utilizando ESP32, driver PCA9685 e servomotores.  
2. Implementar a comunicação entre o ESP32 e o ROS via rede sem fio (Wi-Fi/Bluetooth).  
3. Desenvolver algoritmos de controle para movimentação dos graus de liberdade do braço robótico.  
4. Simular o funcionamento do protótipo no ambiente Gazebo, garantindo validação prévia antes da implementação física.  
5. Realizar a integração prática do sistema físico com o ROS, validando a correspondência entre o protótipo e o modelo simulado.  
6. Oferecer uma alternativa de baixo custo que possibilite a aplicação do braço robótico em contextos educacionais e em pequenas linhas de produção.

## Diagrama de blocos

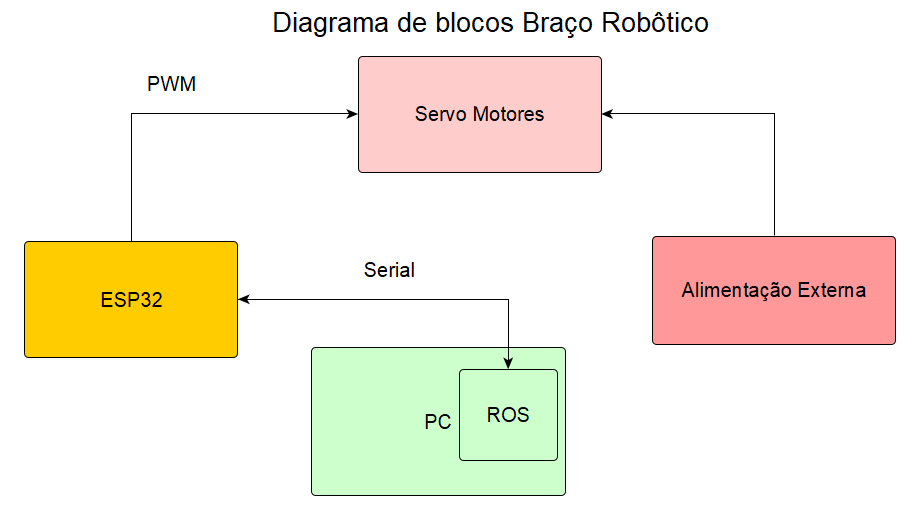
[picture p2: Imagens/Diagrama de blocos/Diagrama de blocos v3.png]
Diagrama_de_blocos_v1


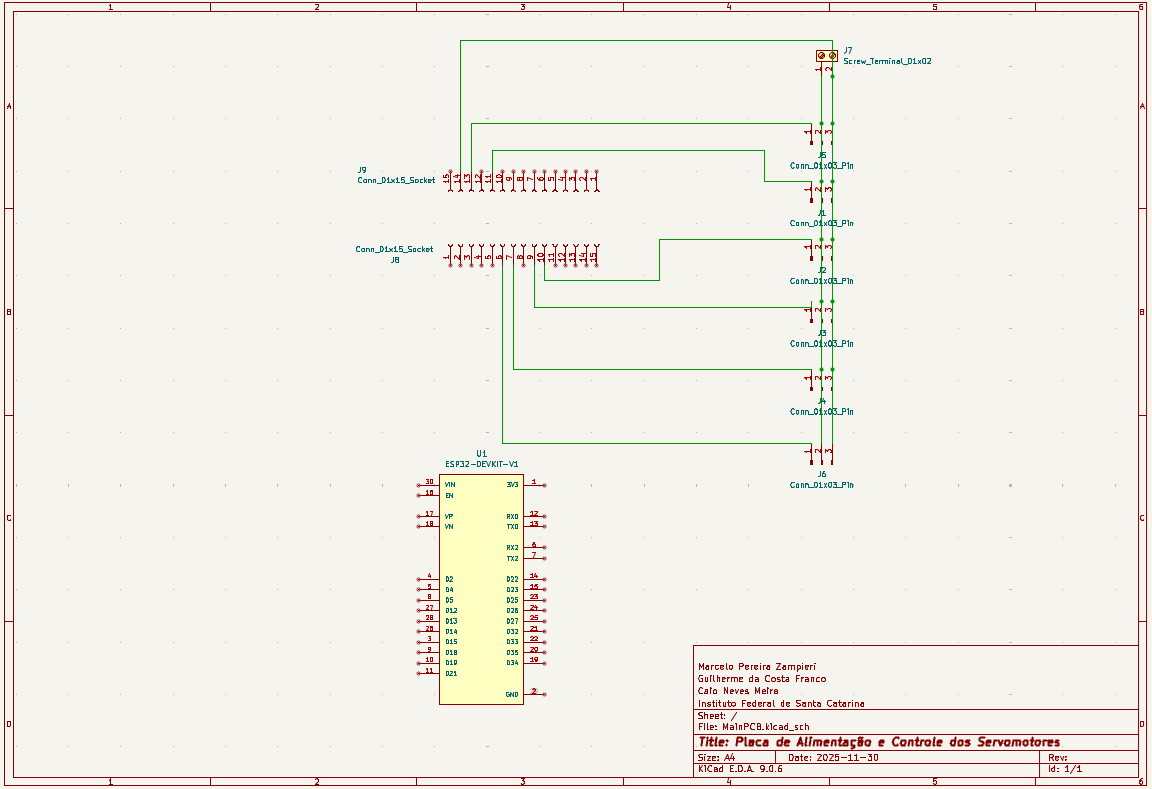
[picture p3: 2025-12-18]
PCI/Esquematico_PCI.png

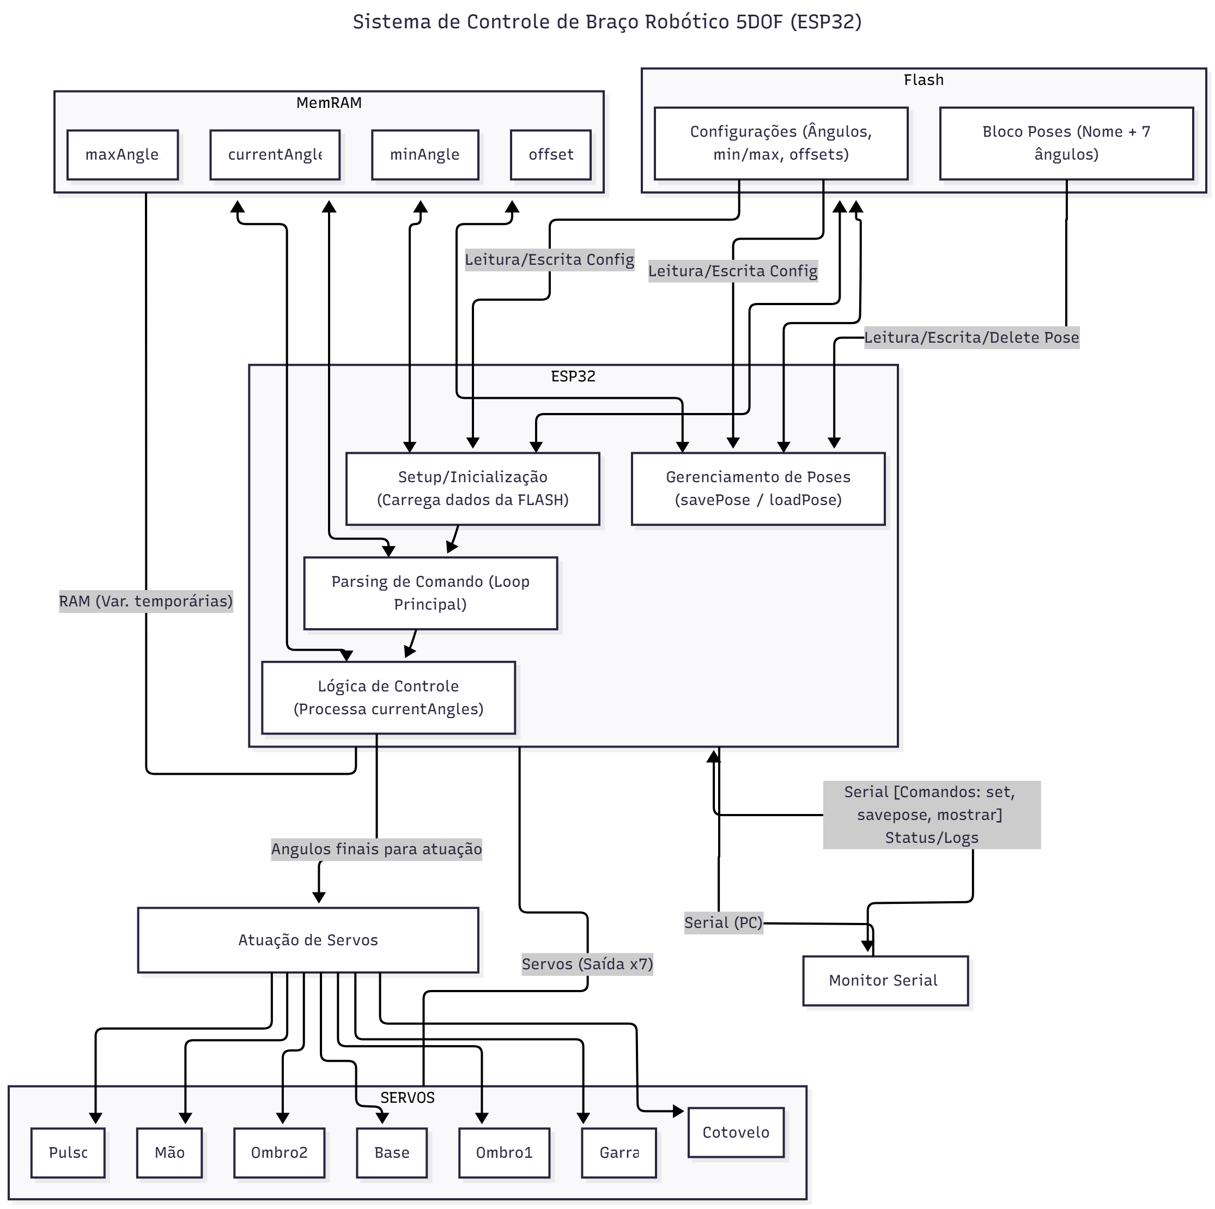
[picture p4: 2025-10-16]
Imagens/Diagrama de blocos/Diagrama de blocos 1ºcod.png

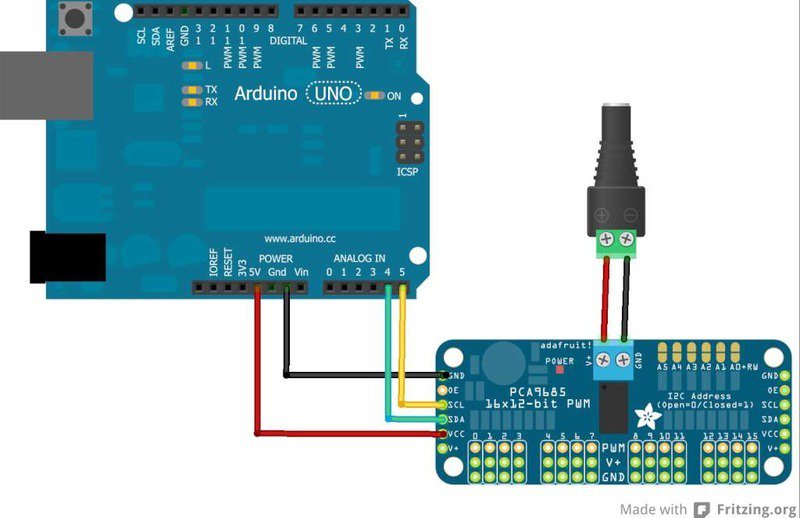
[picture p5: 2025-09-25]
Imagens/PCA9685/modulo-circuito1.jpg

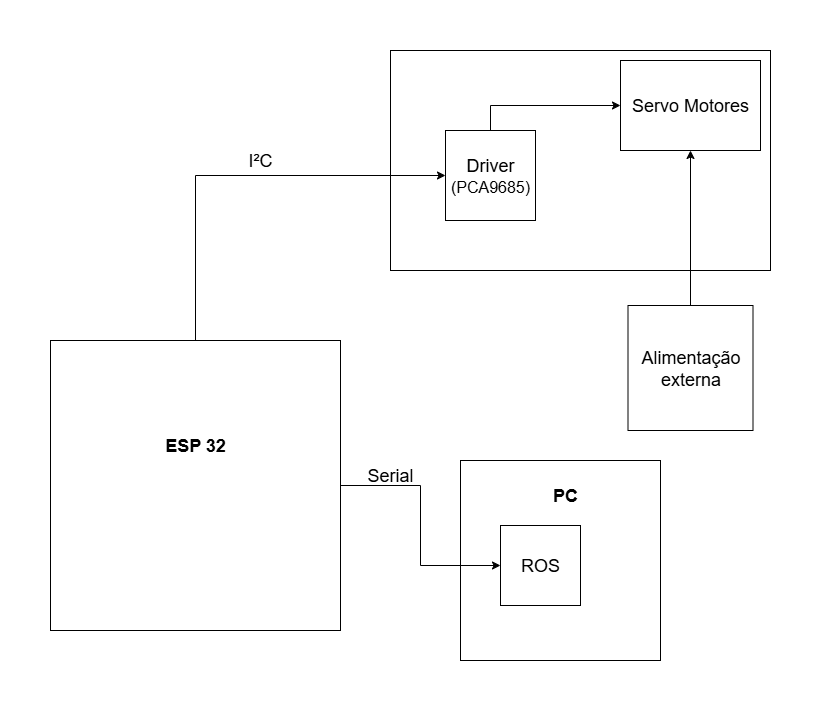
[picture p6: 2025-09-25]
Imagens/Diagrama de blocos/Diagrama de blocos v2.png

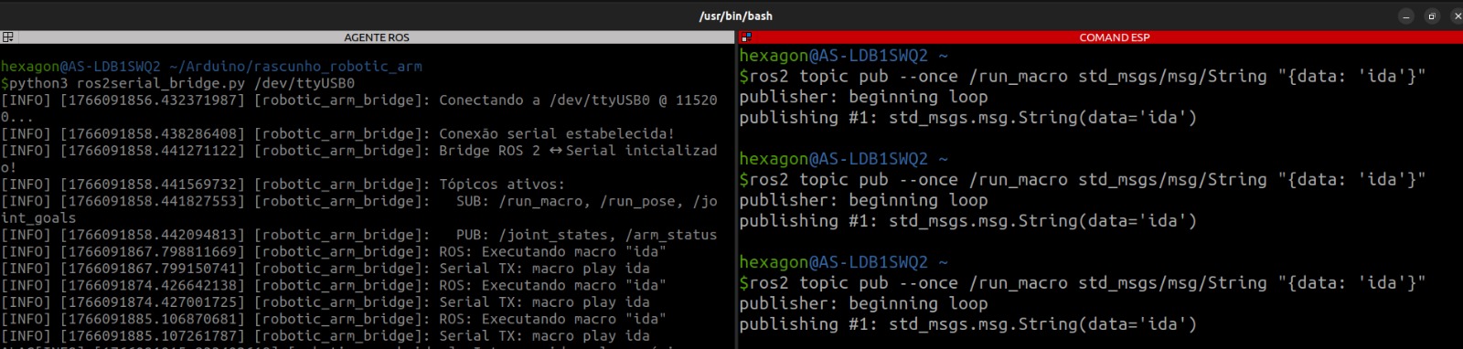
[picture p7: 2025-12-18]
Imagens/UserView/userview.jpg

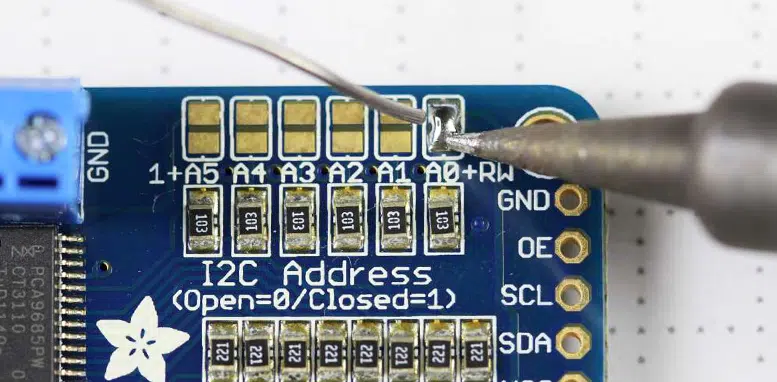
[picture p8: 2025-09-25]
Imagens/PCA9685/adafruit_products_2012_10_13_IMG_0692-1024.png.webp

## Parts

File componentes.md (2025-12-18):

# Componentes e Justificativas Técnicas

## 1. Microcontrolador ESP32 e Mapeamento dos Servomotores

### Por que escolher o ESP32 para controle de braço robótico

O ESP32 é uma excelente escolha para sistemas embarcados em robótica, especialmente para braços robóticos com múltiplos graus de liberdade. Ele oferece:

- **Conectividade integrada (Wi-Fi + Bluetooth)**  
  Ideal para controle remoto, integração com ROS via rede local, atualizações OTA e comunicação com interfaces web ou móveis.

- **Alto desempenho computacional**  
  Processador dual-core com clock de até 240 MHz, suporte a multitarefa via FreeRTOS, e memória suficiente para controle de servos, leitura de sensores e comunicação com ROS.

- **Recursos periféricos robustos**  
  GPIOs abundantes, suporte a PWM, ADCs, SPI, I²C, UARTs, permitindo controle direto de servos, leitura de sensores analógicos/digitais e comunicação com periféricos externos.

- **Ecossistema maduro e flexível**  
  Compatível com Arduino IDE, PlatformIO e ESP-IDF. Possui ampla documentação, bibliotecas e comunidade ativa — facilitando prototipagem, debugging e integração com ROS/micro-ROS.

### Recomendações de integração com servomotores

- Utilizar o ESP32 para controle lógico, leitura de sensores e comunicação com ROS.
- Alimentar os servos separadamente do ESP32, conectando os GNDs em comum. Use fontes com corrente suficiente para picos de consumo (stall current).
- Verificar se os sinais de controle de 3.3V do ESP32 são compatíveis com os servos. Caso contrário, utilizar level shifters para garantir integridade de sinal.

---

### Mapeamento proposto dos servos

Com base nos modelos disponíveis (2× SG90, 3× HXT/HX5010, 2× HK15328D), segue uma sugestão de alocação:

| Servo (modelo) | Articulação aplicada | Justificativa técnica |
| --- | --- | --- |
| SG90 (micro servo) | Garra (abertura/fechamento) | Leve, barato, torque suficiente para movimentos de baixa carga. Ideal para garras pequenas. |
| SG90 (ou similar) | Rotação da “cabeça” (leve)  | Adequado para movimentos estéticos ou de sensores leves. Se houver carga maior, prefira servo padrão. |
| HX5010 / HXT5010 | Cotovelo / rotação da base  | Servo padrão com torque médio-alto. Ideal para articulações que sustentam peso ou movimentam o braço. |
| HK15328D (digital hi-torque) | Ombro (2 unidades) | Servo robusto com engrenagens metálicas e controle digital. Ideal para articulações com alta inércia. |

### Considerações sobre consumo e alimentação dos servos

- **Corrente de operação vs. corrente de stall:**  
  Cada servo possui uma corrente de operação típica (quando em movimento sem carga máxima) e uma corrente de *stall*.  
  - SG90: ~200–250 mA em operação, até ~650 mA em stall.  
  - HX5010: ~500–700 mA em operação, até ~2 A em stall.  
  - HK15328D: ~1–1.5 A em operação, podendo ultrapassar 3 A em stall.  

- **Impacto no projeto:**  
  Com **7 servos ao todo**, se vários se moverem simultaneamente, a corrente instantânea pode passar facilmente de **6–8 A** em picos. Por isso:  
  - Não é recomendável alimentar os servos pela porta USB do ESP32.  
  - Utilizar uma **fonte dedicada para os servos**, com margem de corrente.  
  - Separar a alimentação do ESP32 (5V regulado ou 3.3V) da linha de potência dos servos, unindo apenas o **GND comum**.  

- **Estabilidade:**  
  Para reduzir ruídos e quedas de tensão:  
  - Usar cabos de bitola adequada para a corrente total.  
  - Distribuir a alimentação em barramentos ou hubs, evitando que todos os servos puxem corrente pelo mesmo fio fino.  

- **Sugestão prática:**  
  - Fonte de bancada regulável (12 V + regulador DC-DC step-down para 5–6 V) para fase de protótipo.  
  - Baterias LiPo (ex.: 2S ou 3S com BEC regulando para 5–6 V).
  - Fontes chaveadas de 5 V e, no mínimo, 3 A.

> Nota: **Corrente de stall** é aquela que o motor consome quando está travado (tentando girar, mas sem conseguir). Geralmente, essa corrente é significativamente maior que a corrente de operação normal.
---

## 2. ROS no Projeto — Integração com ESP32

### Visão geral

O ROS (Robot Operating System) é uma plataforma amplamente utilizada para desenvolvimento de sistemas robóticos modulares e escaláveis. Ele oferece uma arquitetura baseada em nós, tópicos e serviços, permitindo que diferentes componentes de um robô se comuniquem de forma eficiente. Para integrar microcontroladores como o ESP32 ao ROS, existem duas abordagens principais, cada uma com suas vantagens e limitações.

---

### Opções de integração com ROS

Durante as pesquisas realizadas, identificaram-se duas formas principais de conectar o ESP32 ao ROS:

---

#### 1. micro-ROS (recomendado para ROS 2)

micro-ROS é uma extensão do ROS 2 voltada para microcontroladores com recursos limitados. Ele permite que o ESP32 funcione como um nó ROS 2 completo, publicando e assinando tópicos, utilizando serviços e participando da rede ROS 2.

**Principais características:**

- Compatível com FreeRTOS, que é amplamente suportado pelo ESP32.
- Suporte a transporte via UDP, Wi-Fi ou serial, permitindo flexibilidade na comunicação.
- Utiliza o protocolo DDS-XRCE, que é otimizado para dispositivos embarcados.
- Comunicação baseada em arquitetura Client-Agent, onde o ESP32 (Client) se comunica com um agente ROS 2 rodando no PC ou Raspberry Pi.

**Vantagens:**

- Integração nativa com ROS 2, sem necessidade de conversões ou adaptações.
- Suporte contínuo da comunidade ROS 2 e atualizações regulares.
- Permite escalabilidade e modularidade para sistemas mais complexos.
- Suporte a múltiplos tipos de transporte (Wi-Fi, serial, Ethernet).

**Desvantagens:**

- Curva de aprendizado um pouco maior para iniciantes.
- Requer configuração do ambiente ROS 2 e compilação cruzada do firmware.

**Exemplo de fluxo de trabalho:**

1. Instalar ROS 2 (ex.: Humble) no PC ou Raspberry Pi.
2. Criar e compilar o workspace do micro-ROS Agent.
3. Configurar e compilar o firmware micro-ROS para ESP32 (via Arduino IDE, PlatformIO ou ESP-IDF).
4. Estabelecer comunicação entre ESP32 e Agent via Wi-Fi ou USB.
5. Publicar/assinar tópicos ROS 2 diretamente do ESP32.

Referência prática: [Tutorial micro-ROS com ESP32](https://www.hackster.io/514301/micro-ros-on-esp32-using-arduino-ide-1360ca)

---

#### 2. rosserial (alternativa para ROS 1)

rosserial é uma biblioteca que permite que microcontroladores comuniquem-se com ROS 1 via uma conexão serial (USB, UART, etc.). O microcontrolador atua como um nó ROS simplificado, e o PC executa o rosserial_server que traduz os dados para a rede ROS.

**Principais características:**

- Comunicação baseada em protocolo serial com encapsulamento de mensagens ROS.
- Suporte a microcontroladores Arduino-like, incluindo ESP32 (com adaptações).
- Utiliza arquitetura cliente-servidor, semelhante ao micro-ROS.

**Vantagens:**

- Simples de implementar, ideal para protótipos rápidos.
- Boa documentação para ROS 1 e Arduino IDE.
- Menor complexidade de configuração inicial.

**Desvantagens:**

- Suporte limitado para ROS 2.
- Instabilidade em algumas placas ESP32 (reboots, perda de pacotes).
- Menor eficiência e escalabilidade comparado ao micro-ROS.
- Dependência de conexão serial, o que limita mobilidade e flexibilidade.

**Quando usar rosserial:**

- Projetos simples baseados em ROS 1.
- Protótipos com poucos nós e baixa demanda de comunicação.
- Situações onde o tempo de desenvolvimento é curto e a confiabilidade não é crítica.

Referência técnica: [Comparação micro-ROS vs rosserial](https://micro.ros.org/docs/concepts/middleware/rosserial/)

---

### Comparativo resumido

| Critério | micro-ROS (ROS 2) | rosserial (ROS 1) |
| --- | --- | --- |
| Compatibilidade | ROS 2 | ROS 1 |
| Transporte | UDP, Wi-Fi, Serial, Ethernet | Serial (USB/UART) |
| Arquitetura | Client-Agent (DDS-XRCE) | Cliente-Servidor (ROS messages) |
| Suporte a ESP32 | Sim (via FreeRTOS) | Sim (com adaptações) |
| Escalabilidade | Alta | Baixa |
| Estabilidade | Alta | Média (instável em ESP32) |
| Complexidade de setup | Moderada | Baixa |
| Comunidade e futuro | Ativo e em expansão | Legado, com suporte limitado |

---

### Recomendação para o projeto

- Se o projeto utilizar ROS 2, a escolha ideal é o micro-ROS, pois oferece integração nativa, maior estabilidade e suporte futuro.
- Se o projeto for baseado em ROS 1 e tiver foco em prototipagem rápida, o rosserial pode ser utilizado, com atenção às limitações de estabilidade no ESP32.

### Arquitetura sugerida

```plaintext
[ PC / Raspberry Pi ]
        ↑
  micro-ROS Agent
        ↑
     [ ESP32 ]
        ↓
      Servos
```

- **PC/RPi**: Planejamento, visualização (RViz), simulação (Gazebo), interface de usuário.
- **ESP32**: Controle embarcado, leitura de sensores, geração de setpoints, controle local (PID).
- **Micro-ROS Agent**: Ponte entre ROS2 e ESP32 via Wi-Fi ou USB.

### Simulação com Gazebo

- Modelar o braço em URDF e simule no Gazebo para validar movimentos, colisões e controladores.
- A integração ROS ↔ Gazebo é padrão e permite testes antes da montagem física.

---

## Checklist de Implementação

- [x] Criar `componentes.md` com este conteúdo.
- [x] Verificar torque e peso das partes mecânicas (consultar datasheets).
- [x] Escolher entre ROS1 (rosserial) ou ROS2 (micro-ROS).
- [x] Planejar fonte de alimentação com margem para picos.
- [ ] Modelar URDF e testar no Gazebo.

---

## Referências Técnicas (colocar links depois)

- ESP32 datasheet e overview
- TowerPro SG90 (micro-servo) — specs / datasheet
- HXT/HX5010 (servo standard de torque médio-alto) — exemplos de specs
- HK15328D (hi-torque digital) — página do produto
- PCA9685 16-channel PWM/servo driver (Adafruit guide)
- micro-ROS (ESP32 port + tutoriais)
- rosserial (wiki/tutorial para microcontroladores)

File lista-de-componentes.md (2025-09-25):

### Lista de Componentes Preliminar

 - 1x Microcontrolador ESP32;
 - 1x Servo-motor SG90;
 - 1x Servo-motor HX5010 / HXT5010;
 - 1x Servo-motor HK15328D;
 - 1x Modulo PWM PCA9685;
 - 6x Sensores de efeito Hall(?)
 - 1x LED Vermelho;
 - 1x LED Verde;
 - 1x LED Amarelo;
 - 1x Protoboard 400 Pontos;
 - 3x Kit Jumpers 10cm x120 Unidades;
 - 3x Res 1k;
 - ~5x Pilhas AA 1,5V;~
 - ~1x Suporte para 4 pilhas AA;~
 - ~2x Barras de pino Macho/Macho;~
 - ~2x Barras de pino Macho/Femea;~
 - ~3x Borne de duas entradas para conexão VCC e GND;~

### Informações sobre os Componentes

#### **Microcontrolador ESP32:** Responsável pelos interpretar todos os dados recebidos, e agir de acordo com as funções definidas no código.
- [ESP32 Doit Devkit V1](https://www.saravati.com.br/placa-esp32-wifi-bluetooth-devkit-v1-30-pinos.html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)

#### **Servo-motores:** Utilizados para manipular o braço robótico apartir de uma instrução recebida.
- [Servo SG90](https://www.filipeflop.com/produto/servo-towerpro-mg995-metalico/)
      
- [Servo HXT5010](https://www.filipeflop.com/produto/servo-towerpro-mg995-metalico/)

- [Servo HK15328D](https://www.filipeflop.com/produto/servo-towerpro-mg995-metalico/)

#### **Leds:** Diodos emissores de luz.

- [LED Vermelho](https://www.makerhero.com/produto/led-difuso-5mm-vermelho/)

- [LED Amarelo](https://www.makerhero.com/produto/led-difuso-5mm-amarelo/)
      
- [LED Verde](https://www.makerhero.com/produto/led-difuso-5mm-verde/)

#### **Módulo PCA9685:** PWM por i2C utilizado para controlar multiplos servos.

- [PCA9685](https://www.makerhero.com/produto/modulo-i2c-pwm-servo-16-canais-pca9685/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)

#### **Componentes Adicionais:** Utilizados para o protótipo ou confecção das PCBS

- [Protoboard 400 Pontos](https://www.makerhero.com/produto/protoboard-400-pontos/)

- [Kit Jumpers](https://www.makerhero.com/produto/kit-jumpers-10cm-x120-unidades/)
 
- [Suporte 4 Pilhas AA](https://www.makerhero.com/produto/suporte-4-pilhas-aa/)

### Exemplo Controle dos Servos utlizando o PCA9685

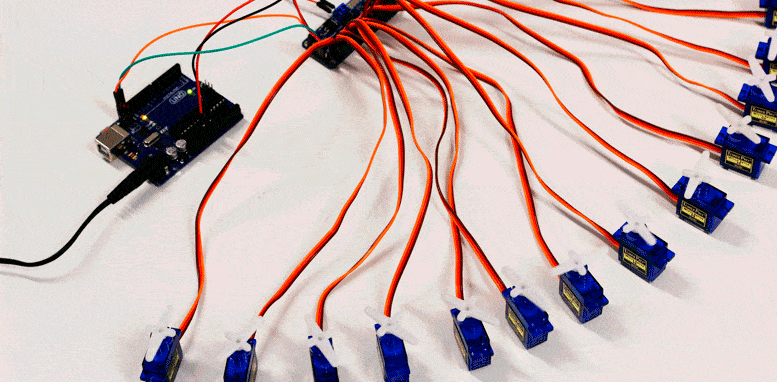
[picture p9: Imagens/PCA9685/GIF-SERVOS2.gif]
Exemplo controle dos Servos pelo PCA9685


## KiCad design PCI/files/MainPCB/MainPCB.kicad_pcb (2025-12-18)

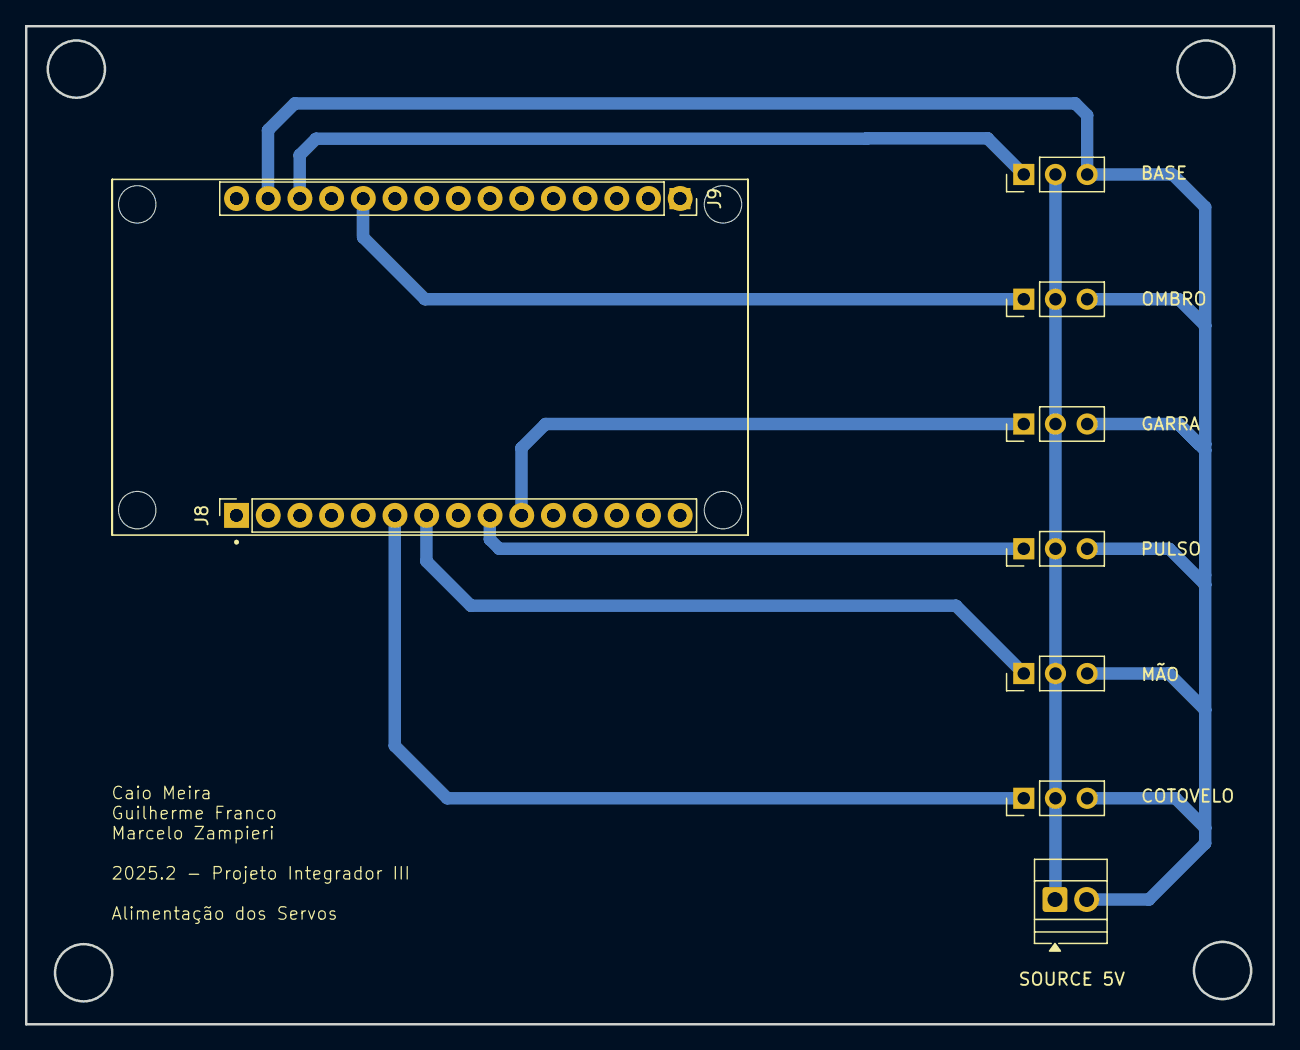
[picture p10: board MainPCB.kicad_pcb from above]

Board: 2 copper layers, 100.0 x 80.0 mm, 9 parts (0 on the bottom side), 8 nets.

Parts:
BASE: Conn_01x03_Pin; PinHeader_1x03_P2.54mm_Vertical
COTOVELO: Conn_01x03_Pin; PinHeader_1x03_P2.54mm_Vertical
GARRA: Conn_01x03_Pin; PinHeader_1x03_P2.54mm_Vertical
J8, J9: Conn_01x15_Socket; PinSocket_1x15_P2.54mm_Vertical
MÃO: Conn_01x03_Pin; PinHeader_1x03_P2.54mm_Vertical
OMBRO: Conn_01x03_Pin; PinHeader_1x03_P2.54mm_Vertical
PULSO: Conn_01x03_Pin; PinHeader_1x03_P2.54mm_Vertical
SOURCE 5V: Screw_Terminal_01x02; TerminalBlock_Xinya_XY308-2.54-2P_1x02_P2.54mm_Horizontal

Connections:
unnamed: J9.11, OMBRO.1
unnamed: BASE.2, COTOVELO.2, GARRA.2, MÃO.2, OMBRO.2, PULSO.2, SOURCE 5V.1
unnamed: BASE.3, COTOVELO.3, GARRA.3, J9.14, MÃO.3, OMBRO.3, PULSO.3, SOURCE 5V.2
unnamed: GARRA.1, J8.10
unnamed: J8.9, PULSO.1
unnamed: J8.7, MÃO.1
unnamed: BASE.1, J9.13
unnamed: COTOVELO.1, J8.6

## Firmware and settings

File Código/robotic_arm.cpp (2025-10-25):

#include <EEPROM.h>
#include <ESP32Servo.h>

// --- Configurações Globais ---
const int NUM_SERVOS = 7; // [0]Base, [1]Ombro1, [2]Ombro2, [3]Cotovelo, [4]Mão, [5]Pulso, [6]Garra
Servo servos[NUM_SERVOS];
int servoPins[NUM_SERVOS] = {13, 14, 15, 16, 17, 18, 19};

// --- Variáveis de Estado e Calibração ---
int currentAngles[NUM_SERVOS]; /**< Última posição lógica interpolada de cada servo (0-180°). */
int minAngles[NUM_SERVOS];     /**< Ângulo mínimo permitido (limite de software). */
int maxAngles[NUM_SERVOS];     /**< Ângulo máximo permitido (limite de software). */
int offsets[NUM_SERVOS];       /**< Offset de calibração aplicado antes de escrever no servo (-90 a +90). */

// --- Configurações de EEPROM e Poses ---
const int MAX_POSES = 10;          /**< Número máximo de poses que podem ser salvas. */
const int POSE_NAME_LEN = 10;      /**< Tamanho máximo do nome da pose. */
const int EEPROM_SIZE = 4096;      /**< Tamanho da memória EEPROM virtual do ESP32. */
const uint32_t EEPROM_MAGIC = 0xDEADBEEF; /**< Número mágico para validar dados na EEPROM. */

// --- Configuração de Velocidade ---
// Define a velocidade padrão em milissegundos por grau.
const int DEFAULT_SPEED_MS_PER_DEGREE = 25; /**< 25 ms por 1 grau de movimento. */
const int MIN_MOVE_DURATION = 300;         /**< Duração mínima para qualquer movimento suave (em ms). */

/**
 * @brief Estrutura para salvar o estado de calibração e posição na EEPROM.
 */
struct StoredData {
  uint32_t magic;           /**< Identificador de dados válidos. */
  int current[NUM_SERVOS];  /**< Última posição conhecida. */
  int minv[NUM_SERVOS];     /**< Limites mínimos. */
  int maxv[NUM_SERVOS];     /**< Limites máximos. */
  int offs[NUM_SERVOS];     /**< Offsets de calibração. */
};

/**
 * @brief Estrutura para salvar uma pose (conjunto de ângulos).
 */
struct Pose {
  char name[POSE_NAME_LEN];   /**< Nome da pose. */
  int angles[NUM_SERVOS];     /**< Ângulos para cada servo. */
};

const int POSES_START = sizeof(StoredData); /**< Endereço inicial de armazenamento das Poses. */

// --- Variáveis de Controle de Movimento Suave ---
bool isMoving = false;             /**< Flag que indica se há um movimento ativo em progresso. */
unsigned long moveStartTime;       /**< Timestamp em ms quando o movimento foi iniciado ou reiniciado. */
unsigned long moveDuration;        /**< Duração total (em ms) do movimento atual. */
int startAngles[NUM_SERVOS];       /**< Posição de cada servo no início do movimento. */
int targetAngles[NUM_SERVOS];      /**< Posição final desejada para cada servo. */

// =================================================================
// FUNÇÕES DE MOVIMENTO CONCORRENTE
// =================================================================

/**
 * @brief Calcula a duração necessária para um movimento com base na velocidade padrão.
 * * A duração é determinada pelo servo que tiver a maior diferença de ângulo
 * entre a posição atual (`currentAngles`) e o novo destino.
 * * @param newTargetAngles Array de 7 elementos com os novos ângulos de destino.
 * @return unsigned long Duração calculada do movimento em milissegundos (ms).
 */
unsigned long calculateDurationBySpeed(const int newTargetAngles[NUM_SERVOS]) {
  int maxDelta = 0;
  for (int i = 0; i < NUM_SERVOS; i++) {
    // Calcula o delta entre a POSIÇÃO LÓGICA ATUAL e o NOVO DESTINO
    int delta = abs(constrain(newTargetAngles[i], minAngles[i], maxAngles[i]) - currentAngles[i]);
    if (delta > maxDelta) {
      maxDelta = delta;
    }
  }
  unsigned long duration = (unsigned long)maxDelta * DEFAULT_SPEED_MS_PER_DEGREE;
  if (duration < MIN_MOVE_DURATION) {
    duration = MIN_MOVE_DURATION;
  }
  return duration;
}

/**
 * @brief Inicia ou atualiza um movimento suave para um novo destino.
 * * Esta função implementa a concorrência: se um movimento já está em andamento,
 * ele é imediatamente interrompido e um NOVO movimento é iniciado a partir da 
 * posição atual (`currentAngles`) em direção ao `newTargetAngles`.
 * * @param newTargetAngles Array de 7 elementos com os novos ângulos de destino.
 * @param duration Duração do novo movimento em milissegundos.
 */
void startSmoothMove(const int newTargetAngles[NUM_SERVOS], unsigned long duration) {
  if (duration == 0) { 
    // Movimento instantâneo
    for (int i = 0; i < NUM_SERVOS; i++) {
      currentAngles[i] = constrain(newTargetAngles[i], minAngles[i], maxAngles[i]);
      int correctedAngle = constrain(currentAngles[i] + offsets[i], 0, 180);
      servos[i].write(correctedAngle);
    }
    isMoving = false;
    Serial.println("✅ Movimento instantâneo concluído.");
    return;
  }
  
  // O ponto de partida é a posição atual (`currentAngles`), mesmo que seja um valor
  // interpolado de um movimento anterior que estava em progresso.
  moveStartTime = millis();
  moveDuration = duration;
  for (int i = 0; i < NUM_SERVOS; i++) {
    startAngles[i] = currentAngles[i];
    targetAngles[i] = constrain(newTargetAngles[i], minAngles[i], maxAngles[i]);
  }
  isMoving = true;
}


/**
 * @brief Executa a interpolação suave (easing) de todos os servos.
 * * Esta função deve ser chamada repetidamente no `loop()`. Ela calcula a posição 
 * atual de cada servo com base no tempo decorrido, aplicando uma curva de 
 * suavização Quadrática (Ease In/Out).
 */
void updateSmoothMovement() {
  if (!isMoving) return;
  unsigned long elapsedTime = millis() - moveStartTime;

  if (elapsedTime >= moveDuration) {
    // 1. Movimento concluído: Garante a posição final
    for (int i = 0; i < NUM_SERVOS; i++) {
      currentAngles[i] = targetAngles[i];
      int correctedAngle = constrain(currentAngles[i] + offsets[i], 0, 180);
      servos[i].write(correctedAngle);
    }
    isMoving = false;
    Serial.println("✅ Movimento concluído.");
  } else {
    // 2. Interpolação em progresso:
    float progress = (float)elapsedTime / (float)moveDuration;
    float easeProgress;

    // Função de Easing (Quadrático In/Out) para aceleração/desaceleração suave
    if (progress < 0.5f) {
      easeProgress = 2.0f * progress * progress; // EaseIn (aceleração)
    } else {
      // EaseOut (desaceleração)
      float t = -2.0f * progress + 2.0f;
      easeProgress = 1.0f - (t * t) / 2.0f; 
    }
    
    // Interpola a posição para cada servo
    for (int i = 0; i < NUM_SERVOS; i++) {
      int interpolatedAngle = startAngles[i] + (targetAngles[i] - startAngles[i]) * easeProgress;
      currentAngles[i] = interpolatedAngle; 
      int correctedAngle = constrain(interpolatedAngle + offsets[i], 0, 180);
      servos[i].write(correctedAngle);
    }
  }
}

// =================================================================
// FUNÇÕES DE EEPROM E POSE
// =================================================================

/**
 * @brief Salva o estado atual do braço (ângulos, limites, offsets) na EEPROM.
 */
void saveToEEPROM() {
  StoredData sd;
  sd.magic = EEPROM_MAGIC;
  for (int i = 0; i < NUM_SERVOS; i++) {
    sd.current[i] = currentAngles[i];
    sd.minv[i] = minAngles[i];
    sd.maxv[i] = maxAngles[i];
    sd.offs[i] = offsets[i];
  }
  EEPROM.put(0, sd);
  EEPROM.commit();
  Serial.println("💾 Posições, limites e offsets salvos na EEPROM.");
}

/**
 * @brief Carrega o estado de calibração e a última posição salva da EEPROM.
 * * Se for bem-sucedido, inicia um movimento suave da posição de setup para a 
 * posição restaurada.
 * * @return true Se os dados foram carregados e validados.
 * @return false Se a EEPROM estiver vazia ou inválida.
 */
bool loadFromEEPROM() {
  StoredData sd;
  EEPROM.get(0, sd);
  if (sd.magic != EEPROM_MAGIC) return false;

  int initialAngles[NUM_SERVOS];
  for (int i = 0; i < NUM_SERVOS; i++) {
    minAngles[i] = constrain(sd.minv[i], 0, 180);
    maxAngles[i] = constrain(sd.maxv[i], 0, 180);
    offsets[i] = constrain(sd.offs[i], -180, 180);
    initialAngles[i] = sd.current[i];
  }
  
  unsigned long autoDuration = calculateDurationBySpeed(initialAngles);
  Serial.printf("✅ Restaurando posição da EEPROM em %lu ms...\n", autoDuration);
  startSmoothMove(initialAngles, autoDuration); 
  
  Serial.println("✅ Posições, limites e offsets restaurados da EEPROM.");
  return true;
}

/**
 * @brief Salva a posição atual (`currentAngles`) em um slot de pose.
 * * Se o nome já existir, a pose é sobrescrita.
 * * @param name Nome da pose a ser salva.
 */
void savePose(String name) {
  if (name.length() > POSE_NAME_LEN - 1) name = name.substring(0, POSE_NAME_LEN - 1);
  char cname[POSE_NAME_LEN];
  name.toCharArray(cname, POSE_NAME_LEN);

  for (int i = 0; i < MAX_POSES; i++) {
    Pose p;
    EEPROM.get(POSES_START + i * sizeof(Pose), p);
    // Verifica se o slot está vazio (p.name[0] == 0) ou se o nome já existe (sobrescreve)
    if (p.name[0] == 0 || strncmp(p.name, cname, POSE_NAME_LEN) == 0) {
      strncpy(p.name, cname, POSE_NAME_LEN);
      for (int j = 0; j < NUM_SERVOS; j++) p.angles[j] = currentAngles[j];
      EEPROM.put(POSES_START + i * sizeof(Pose), p);
      EEPROM.commit();
      Serial.printf("Pose '%s' salva na posição %d\n", cname, i);
      return;
    }
  }
  Serial.println("⚠️ Limite de poses atingido.");
}

/**
 * @brief Carrega uma pose salva e inicia um movimento suave para essa pose.
 * * O movimento é imediato e concorre com qualquer movimento anterior.
 * * @param name Nome da pose a ser carregada.
 * @param duration Duração opcional do movimento (0 para calcular automaticamente).
 * @return true Se a pose foi encontrada e o movimento iniciado.
 * @return false Se a pose não foi encontrada.
 */
bool loadPose(String name, unsigned long duration) {
  if (name.length() > POSE_NAME_LEN - 1) name = name.substring(0, POSE_NAME_LEN - 1);
  char cname[POSE_NAME_LEN];
  name.toCharArray(cname, POSE_NAME_LEN);

  for (int i = 0; i < MAX_POSES; i++) {
    Pose p;
    EEPROM.get(POSES_START + i * sizeof(Pose), p);
    if (p.name[0] != 0 && strncmp(p.name, cname, POSE_NAME_LEN) == 0) {
      
      if (duration == 0) {
        duration = calculateDurationBySpeed(p.angles);
      }
      
      Serial.printf("Carregando pose '%s' em %lu ms (Movimento Concorrente)....\n", cname, duration);
      startSmoothMove(p.angles, duration); 
      return true;
    }
  }
  Serial.printf("Pose '%s' não encontrada\n", cname);
  return false;
}

/**
 * @brief Deleta uma pose da EEPROM.
 * * @param name Nome da pose a ser deletada.
 */
void deletePose(String name) {
    if (name.length() > POSE_NAME_LEN - 1) name = name.substring(0, POSE_NAME_LEN - 1);
    char cname[POSE_NAME_LEN];
    name.toCharArray(cname, POSE_NAME_LEN);

    for (int i = 0; i < MAX_POSES; i++) {
        Pose p;
        EEPROM.get(POSES_START + i * sizeof(Pose), p);
        if (strncmp(p.name, cname, POSE_NAME_LEN) == 0) {
            memset(&p, 0, sizeof(Pose)); // Limpa o slot
            EEPROM.put(POSES_START + i * sizeof(Pose), p);
            EEPROM.commit();
            Serial.printf("Pose '%s' deletada.\n", cname);
            return;
        }
    }
    Serial.printf("Pose '%s' não encontrada para deletar.\n", cname);
}

// --- Funções Auxiliares (Listar, Ajuda, etc.) ---
void listPoses() {
  Serial.println("\nPoses salvas na EEPROM:");
  int count = 0;
  for (int i = 0; i < MAX_POSES; i++) {
    Pose p;
    EEPROM.get(POSES_START + i * sizeof(Pose), p);
    if (p.name[0] != 0) {
      Serial.printf("  - %s\n", p.name);
      count++;
    }
  }
  if (count == 0) Serial.println("  Nenhuma pose encontrada.");
  Serial.printf("Total: %d de %d slots usados.\n", count, MAX_POSES);
}

void printHelp() {
  Serial.println("\n--- Comandos Disponíveis (v5.0 com Movimento Imediato) ---");
  Serial.println("  Todos os comandos de movimento são executados imediatamente e podem ser combinados.");
  Serial.println("  [tempo_ms] é opcional e anula a velocidade padrão.");
  Serial.println("  ---------------------------------------------------------");
  Serial.println("  set <servo> <angulo> [tempo_ms] -> Move servo individual (Imediato)");
  Serial.println("  set ombro <angulo> [tempo_ms]   -> Move os dois servos do ombro (Imediato)");
  Serial.println("  loadpose <nome> [tempo_ms]      -> Carrega pose (Imediato)");
  Serial.println("  align ombro [tempo_ms]          -> Alinha ombros na média (Imediato)");
  Serial.println("  ---------------------------------------------------------");
  Serial.println("  min <servo> <angulo>            -> Define ângulo mínimo (Limites de software)");
  Serial.println("  max <servo> <angulo>            -> Define ângulo máximo (Limites de software)");
  Serial.println("  offset <servo> <valor>          -> Define offset de calibração (-90 a 90)");
  Serial.println("  mostrar                         -> Exibe valores atuais, limites e offsets");
  Serial.println("  listposes                       -> Lista todas as poses salvas");
  Serial.println("  save                            -> Salva estado atual na EEPROM");
  Serial.println("  load                            -> Carrega estado da EEPROM");
  Serial.println("  savepose <nome>                 -> Salva pose atual com um nome");
  Serial.println("  delpose <nome> | all            -> Apaga pose(s)");
  Serial.println("  help                            -> Mostra esta ajuda");
  Serial.println("---------------------------------------------------------");
}

void handleSerialInput(); // Declaração antecipada

// --- SETUP e LOOP ---
void setup() {
  Serial.begin(115200);
  delay(100);
  EEPROM.begin(EEPROM_SIZE);

  // Posições de segurança inicial, usadas se a EEPROM estiver vazia.
  int safeMin[NUM_SERVOS]     = {0, 95, 95, 50, 0, 60, 55};
  int safeMax[NUM_SERVOS]     = {180, 180, 180, 180, 180, 180, 155};
  int safeNeutral[NUM_SERVOS] = {90, 130, 130, 100, 70, 120, 100};

  for (int i = 0; i < NUM_SERVOS; i++) {
    servos[i].attach(servoPins[i]);
    minAngles[i] = safeMin[i];
    maxAngles[i] = safeMax[i];
    offsets[i] = 0;
    currentAngles[i] = safeNeutral[i];
    servos[i].write(constrain(safeNeutral[i] + offsets[i], 0, 180));
    delay(50);
  }

  if (!loadFromEEPROM()) {
    Serial.println("⚠️ EEPROM vazia ou inválida. Usando valores iniciais.");
  }
  
  printHelp();
}

void loop() {
  // 1. Sempre atualiza o movimento em progresso.
  // Esta chamada é crucial para a concorrência e suavização.
  updateSmoothMovement(); 

  // 2. Processa novos comandos seriais imediatamente (não bloqueia).
  handleSerialInput();
}


/**
 * @brief Lógica principal para processar comandos recebidos via porta serial.
 * * Verifica a disponibilidade da serial e analisa a string de comando.
 */
void handleSerialInput() {
  if (!Serial.available()) return;

  String input = Serial.readStringUntil('\n');
  input.trim();
  if (input.length() == 0) return;

  // --- PARSING DE COMANDOS DE CALIBRAÇÃO E EEPROM ---
  if (input.equalsIgnoreCase("mostrar")) {
    for (int i = 0; i < NUM_SERVOS; i++) {
      Serial.printf("Servo %d | atual:%3d | min:%3d | max:%3d | offset:%+3d | out:%3d\n",
        i, currentAngles[i], minAngles[i], maxAngles[i], offsets[i],
        constrain(currentAngles[i] + offsets[i], 0, 180));
    }
  } else if (input.equalsIgnoreCase("listposes")) {
    listPoses();
  } else if (input.startsWith("savepose ")) {
    savePose(input.substring(9));
  } else if (input.startsWith("min ")) {
    int idx, val;
    if (sscanf(input.c_str(), "min %d %d", &idx, &val) == 2 && idx >= 0 && idx < NUM_SERVOS) {
      minAngles[idx] = constrain(val, 0, 180);
      Serial.printf("Mínimo do servo %d definido para %d°\n", idx, val);
    } else Serial.println("Formato inválido.");
  } else if (input.startsWith("max ")) {
    int idx, val;
    if (sscanf(input.c_str(), "max %d %d", &idx, &val) == 2 && idx >= 0 && idx < NUM_SERVOS) {
      maxAngles[idx] = constrain(val, 0, 180);
      Serial.printf("Máximo do servo %d definido para %d°\n", idx, val);
    } else Serial.println("Formato inválido.");
  } else if (input.startsWith("offset ")) {
    int idx, val;
    if (sscanf(input.c_str(), "offset %d %d", &idx, &val) == 2 && idx >= 0 && idx < NUM_SERVOS) {
      offsets[idx] = constrain(val, -90, 90);
      servos[idx].write(constrain(currentAngles[idx] + offsets[idx], 0, 180)); 
      Serial.printf("Offset do servo %d ajustado para %+d°\n", idx, val);
    } else Serial.println("Formato inválido.");
  } else if (input.equalsIgnoreCase("save")) {
    saveToEEPROM();
  } else if (input.equalsIgnoreCase("load")) {
    loadFromEEPROM();
  } else if (input.equalsIgnoreCase("help")) {
    printHelp();
  } else if (input.startsWith("delpose ")) {
    String name = input.substring(8);
    name.trim();
    if (name.equalsIgnoreCase("all")) {
      for (int i = 0; i < MAX_POSES; i++) {
        Pose empty = {0};
        EEPROM.put(POSES_START + i * sizeof(Pose), empty);
      }
      EEPROM.commit();
      Serial.println("Todas as poses foram apagadas.");
    } else {
      deletePose(name);
    }
  } 
  
  // --- PARSING DE COMANDOS DE MOVIMENTO (IMEDIATO/CONCORRENTE) ---
  
  else if (input.startsWith("loadpose ")) {
    char name[POSE_NAME_LEN] = {0};
    unsigned long duration = 0; 
    
    int params = sscanf(input.c_str(), "loadpose %s %lu", name, &duration);
    
    if(params >= 1) {
        loadPose(String(name), duration); 
    } else {
        Serial.println("Formato inválido. Use: loadpose <nome> [tempo_ms]");
    }
  } 
  
  else if (input.startsWith("set ")) {
    // A chave da concorrência: o destino é baseado na posição atual (currentAngles)
    // para que movimentos incompletos sejam continuados/combinados.
    int tempTarget[NUM_SERVOS];
    for(int i=0; i<NUM_SERVOS; i++) tempTarget[i] = currentAngles[i];

    if (input.startsWith("set ombro ")) {
      int angle;
      unsigned long duration = 0; 
      
      sscanf(input.c_str(), "set ombro %d %lu", &angle, &duration);
      
      // Altera múltiplos servos no destino
      tempTarget[1] = angle;
      tempTarget[2] = angle;
      
      if (duration == 0) {
        duration = calculateDurationBySpeed(tempTarget);
      }
      
      Serial.printf("Movendo ombro para %d° em %lu ms (Movimento Concorrente)....\n", angle, duration);
      startSmoothMove(tempTarget, duration);
      
    } else {
      int servo_idx, angle;
      unsigned long duration = 0; 
      int params = sscanf(input.c_str(), "set %d %d %lu", &servo_idx, &angle, &duration);
      
      if (params >= 2 && servo_idx >= 0 && servo_idx < NUM_SERVOS) {
        // Altera apenas um servo no destino
        tempTarget[servo_idx] = angle;
        
        if (duration == 0) {
          duration = calculateDurationBySpeed(tempTarget);
        }
        
        Serial.printf("Movendo servo %d para %d° em %lu ms (Movimento Concorrente)....\n", servo_idx, angle, duration);
        startSmoothMove(tempTarget, duration);
      } else {
        Serial.println("Formato inválido. Use: set <servo> <angulo> [tempo_ms]");
      }
    }
  } 
  
  else if (input.startsWith("align ombro")) {
      unsigned long duration = 0; 
      sscanf(input.c_str(), "align ombro %lu", &duration);
      
      int tempTarget[NUM_SERVOS];
      for(int i=0; i<NUM_SERVOS; i++) tempTarget[i] = currentAngles[i];
      
      int media = (currentAngles[1] + currentAngles[2]) / 2;
      tempTarget[1] = media;
      tempTarget[2] = media;
      
      if (duration == 0) {
        duration = calculateDurationBySpeed(tempTarget);
      }
      
      Serial.printf("Alinhando ombros para %d° em %lu ms (Movimento Concorrente)....\n", media, duration);
      startSmoothMove(tempTarget, duration);
  } 
  
  else {
    Serial.printf("Comando não reconhecido: '%s'\n", input.c_str());
  }
}

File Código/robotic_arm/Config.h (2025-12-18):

// Arquivo de Configurações Globais e Estruturas
// Define todas as constantes, inclui bibliotecas essenciais e declara variáveis globais.

#ifndef CONFIG_H
#define CONFIG_H

#include <Arduino.h>
#include <EEPROM.h>
#include <ESP32Servo.h>

// --- Configurações Globais ---
const int NUM_SERVOS = 7; // [0]Base, [1]Ombro1, [2]Ombro2, [3]Cotovelo, [4]Mão, [5]Pulso, [6]Garra
const int EEPROM_SIZE = 4096;
const uint32_t EEPROM_MAGIC = 0xDEADBEEF;

// Mapeamento dos pinos do ESP32 para cada servo
const int servoPins[NUM_SERVOS] = {18, 4, 13, 27, 26, 33, 32};

// --- Configuração de Poses e Macros ---
const int MAX_POSES = 10;
const int POSE_NAME_LEN = 10;
const int MAX_MACROS = 5;           // Número máximo de rotinas (Macros) que podem ser salvas
const int MAX_STEPS_PER_MACRO = 16; // Número máximo de passos em uma Macro

// --- Configuração de Velocidade ---
const int DEFAULT_SPEED_MS_PER_DEGREE = 25;
const int MIN_MOVE_DURATION = 300;

struct ArmKinematicsConfig
{
  float baseHeightMm;
  float upperLenMm;
  float forearmLenMm;
  float wristOffsetMm;
  float gripperLenMm;
  float minReachMm;
  float maxReachMm;
};

struct NeutralPose
{
  int base;
  int shoulder;
  int elbow;
  int hand;
  int wristRotate;
  int gripper;
};

constexpr ArmKinematicsConfig ARM_KINEMATICS = {
    100.0f, // baseHeightMm
    120.0f, // upperLenMm
    130.0f, // forearmLenMm
    40.0f,  // wristOffsetMm
    50.0f,  // gripperLenMm
    80.0f,  // minReachMm
    330.0f  // maxReachMm
};

constexpr NeutralPose IK_NEUTRAL = {
    90,  // base
    130, // shoulder
    100, // elbow
    70,  // hand
    120, // wristRotate
    100  // gripper
};

// --- Estruturas de Dados ---

/**
 * @brief Estrutura para salvar o estado de calibração e última posição na EEPROM (V1 - LEGACY).
 */
struct StoredData
{
  uint32_t magic;          /**< Identificador de dados válidos. */
  int current[NUM_SERVOS]; /**< Última posição conhecida. */
  int minv[NUM_SERVOS];    /**< Limites mínimos. */
  int maxv[NUM_SERVOS];    /**< Limites máximos. */
  int offs[NUM_SERVOS];    /**< Offsets de calibração. */
};

/**
 * @brief Estrutura OTIMIZADA V2 para salvar estado (35 bytes vs 116 bytes V1).
 * Usa uint8_t para ângulos (0-180° cabe em 1 byte) e inclui CRC16 para validação.
 */
struct StoredDataV2
{
  uint32_t magic;              /**< Identificador de dados válidos (0xDEADBEEF). */
  uint8_t version;             /**< Versão do formato (2). */
  uint8_t current[NUM_SERVOS]; /**< Última posição conhecida (0-180°). */
  uint8_t minv[NUM_SERVOS];    /**< Limites mínimos (0-180°). */
  uint8_t maxv[NUM_SERVOS];    /**< Limites máximos (0-180°). */
  int8_t offs[NUM_SERVOS];     /**< Offsets de calibração (-127 a +127). */
  uint16_t crc16;              /**< CRC16 para validação de integridade. */
} __attribute__((packed));

/**
 * @brief Estrutura para salvar uma pose (conjunto de ângulos) - V1 LEGACY.
 */
struct Pose
{
  char name[POSE_NAME_LEN]; /**< Nome da pose. */
  int angles[NUM_SERVOS];   /**< Ângulos para cada servo. */
};

/**
 * @brief Estrutura OTIMIZADA para pose (8 bytes vs 38 bytes V1).
 */
struct PoseCompact
{
  uint8_t angles[NUM_SERVOS]; /**< Ângulos (0-180°, 1 byte cada). */
  uint8_t flags;              /**< Flags reservadas para uso futuro. */
} __attribute__((packed));

// --- Endereços de Memória (Start) ---
// V1 (LEGACY - compatibilidade temporária)
const int POSES_START = sizeof(StoredData);
const int MACROS_START = POSES_START + (MAX_POSES * sizeof(struct Pose));

// V2 (OTIMIZADO - novo formato)
const int POSES_START_V2 = sizeof(StoredDataV2);
const int MACROS_START_V2 = POSES_START_V2 + (MAX_POSES * sizeof(PoseCompact));

/**
 * @brief Estrutura para definir um único passo dentro de uma Macro - V1 LEGACY.
 */
struct MacroStep
{
  char poseName[POSE_NAME_LEN]; /**< Nome da pose a ser carregada. */
  unsigned long delay_ms;       /**< Tempo de espera após atingir a pose (em ms). */
};

/**
 * @brief Estrutura OTIMIZADA para passo de macro (3 bytes vs 14 bytes V1).
 */
struct MacroStepCompact
{
  uint8_t poseIndex; /**< Índice da pose (0-9 para MAX_POSES=10). */
  uint16_t delay_ms; /**< Delay em ms (0-65535, ~65 segundos). */
} __attribute__((packed));

/**
 * @brief Estrutura para definir uma sequência completa de movimentos e esperas - V1 LEGACY.
 */
struct Macro
{
  char name[POSE_NAME_LEN];             /**< Nome da Macro. */
  int numSteps;                         /**< Número de passos atualmente usados na sequência. */
  MacroStep steps[MAX_STEPS_PER_MACRO]; /**< Lista de passos da rotina. */
};

/**
 * @brief Estrutura OTIMIZADA de Macro (50 bytes vs 238 bytes V1).
 */
struct MacroCompact
{
  uint8_t numSteps;                            /**< Número de passos (0-16). */
  uint8_t flags;                               /**< Flags reservadas. */
  MacroStepCompact steps[MAX_STEPS_PER_MACRO]; /**< Passos compactos. */
} __attribute__((packed));
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

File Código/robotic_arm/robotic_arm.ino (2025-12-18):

/**
 * ROBOTIC ARM - ESP32
 * Versão 5.0 agora vai
 *
 * Ponto de entrada principal.
 * Coordena a inicialização dos módulos e o loop principal.
 */

// Inclui todos os cabeçalhos dos módulos necessários
#include "Config.h"
#include "MotionController.h"
#include "CommandParser.h"
#include "Storage.h"
#include "Sequencer.h"
#include <esp_task_wdt.h>

#include "RosInterface.h"

// Configuração do Watchdog Timer (15 segundos)
// #define WDT_TIMEOUT 15

/**
 * @brief Configuração inicial do sistema.
 */
void setup()
{
  Serial.begin(115200);
  delay(2000); // Aguarda estabilização e sincronização com micro-ROS agent
  Serial.println(F("\nIniciando Sistema do Braco Robotico v5.0..."));
  Serial.flush(); // Limpa buffer de saída

  // Configura o Watchdog Timer
  // esp_task_wdt_init(WDT_TIMEOUT, true); // 15 segundos, panic em timeout
  // esp_task_wdt_add(NULL);               // Adiciona a task atual (loop)
  Serial.println(F("Watchdog Timer configurado (15s)."));

  // Inicializa a memória EEPROM
  EEPROM.begin(EEPROM_SIZE);

  // Carrega calibrações e última pose sem iniciar movimento automático
  const bool hasCalibration = Storage::loadFromEEPROM(false);

  // Configura os servos preservando os dados carregados quando disponíveis
  MotionController::setup(hasCalibration);

  if (hasCalibration)
  {
    Serial.println(F("Calibracao carregada. Servos aguardando comandos."));
  }
  else
  {
    Serial.println(F("AVISO: EEPROM vazia ou inválida. Usando valores de fallback."));
  }

  // Mostra o menu de ajuda inicial
  CommandParser::setup();

  // Inicializa micro-ROS (requer agente ativo via USB)
  //RosInterface::setup();
  Serial.println(F("Sistema inicializado. micro-ROS ativo."));
}

/**
 * @brief Loop principal de execução.
 * Este loop é não-bloqueante e roda o mais rápido possível.
 */
void loop()
{
  // Reset do Watchdog Timer a cada iteração do loop
  // esp_task_wdt_reset();

  // 1. Atualiza a máquina de estados do movimento (interpolação)
  // Isso move fisicamente os servos a cada passo.
  MotionController::update();

  // 2. Atualiza a máquina de estados do sequenciador (macros)
  // Isso verifica se um movimento terminou para iniciar uma espera ou o próximo passo.
  Sequencer::update();

  // 3. Verifica e processa novos comandos da Serial
  // Isso lê a entrada do usuário.
  CommandParser::handleSerialInput();

  // 4. Processa mensagens ROS (subscribers, publishers, timers)
  //RosInterface::update();
}

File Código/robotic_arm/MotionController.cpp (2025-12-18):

/**
 * MotionController.cpp
 * Implementação da lógica de interpolação e controle de servos.
 */
#include "MotionController.h"
#include <Arduino.h>

// --- Variáveis de Estado de Movimento (Internas) ---
// Note: '_isMoving' usa um underscore para evitar conflito de nome
// com a função 'isMoving()'.
static bool _isMoving = false;
static unsigned long moveStartTime;
static unsigned long moveDuration;
static int startAngles[NUM_SERVOS];
static int targetAngles[NUM_SERVOS];

// Objetos de Hardware (definidos aqui, pois este módulo os controla)
Servo servos[NUM_SERVOS];

// Variáveis de Posição (definidas aqui, pois este módulo as controla)
// VALORES INICIAIS AQUI (DEFINIÇÃO) CORRIGEM O ERRO DE LINKER ANTERIOR
int currentAngles[NUM_SERVOS] = {90, 90, 90, 90, 90, 90, 90};
int minAngles[NUM_SERVOS] = {0, 0, 0, 0, 0, 0, 0};
int maxAngles[NUM_SERVOS] = {180, 180, 180, 180, 180, 180, 180};
int offsets[NUM_SERVOS] = {0, 0, 0, 0, 0, 0, 0};

namespace MotionController
{

  /**
   * @brief Inicializa os pinos dos servos, define a posição neutra inicial e
   * configura os limites seguros.
   */
  void setup(bool hasCalibration)
  {
    int safeMin[NUM_SERVOS] = {0, 95, 95, 50, 0, 60, 55};
    int safeMax[NUM_SERVOS] = {180, 180, 180, 180, 180, 180, 155};
    int safeNeutral[NUM_SERVOS] = {90, 130, 130, 100, 70, 120, 100};

    for (int i = 0; i < NUM_SERVOS; i++)
    {
      servos[i].attach(servoPins[i]);

      if (!hasCalibration)
      {
        minAngles[i] = safeMin[i];
        maxAngles[i] = safeMax[i];
        offsets[i] = 0;
        currentAngles[i] = safeNeutral[i];
      }
      else
      {
        minAngles[i] = constrain(minAngles[i], 0, 180);
        maxAngles[i] = constrain(maxAngles[i], minAngles[i], 180);
        currentAngles[i] = constrain(currentAngles[i], minAngles[i], maxAngles[i]);
      }

      const int corrected = constrain(currentAngles[i] + offsets[i], 0, 180);
      servos[i].write(corrected);
      delay(30);
    }
  }

  /**
   * @brief Retorna o estado do movimento.
   */
  bool isMoving()
  {
    return _isMoving;
  }

  /**
   * @brief Calcula a duração ideal do movimento baseado na velocidade padrão.
   */
  unsigned long calculateDurationBySpeed(const int target[NUM_SERVOS])
  {
    int maxDelta = 0;
    // Encontra o servo que tem o maior trajeto a percorrer
    for (int i = 0; i < NUM_SERVOS; i++)
    {
      int delta = abs(target[i] - currentAngles[i]);
      if (delta > maxDelta)
      {
        maxDelta = delta;
      }
    }
    // Calcula a duração e garante que seja pelo menos o mínimo
    unsigned long duration = (unsigned long)maxDelta * DEFAULT_SPEED_MS_PER_DEGREE;
    return max(duration, (unsigned long)MIN_MOVE_DURATION);
  }

  void startSmoothMove(const int newTargetAngles[NUM_SERVOS], unsigned long duration)
  {
    // Validação de servos: verifica se os ângulos estão dentro dos limites permitidos
    for (int i = 0; i < NUM_SERVOS; i++)
    {
      if (newTargetAngles[i] < minAngles[i] || newTargetAngles[i] > maxAngles[i])
      {
        Serial.print(F("ERRO: Servo "));
        Serial.print(i);
        Serial.print(F(" fora dos limites ("));
        Serial.print(minAngles[i]);
        Serial.print(F("-"));
        Serial.print(maxAngles[i]);
        Serial.print(F("). Valor recebido: "));
        Serial.println(newTargetAngles[i]);
        return; // Aborta o movimento se qualquer servo estiver fora dos limites
      }
    }

    // Se a duração for 0, executa o movimento instantâneo
    if (duration == 0)
    {
      for (int i = 0; i < NUM_SERVOS; i++)
      {
        currentAngles[i] = constrain(newTargetAngles[i], minAngles[i], maxAngles[i]);
        int correctedAngle = constrain(currentAngles[i] + offsets[i], 0, 180);
        servos[i].write(correctedAngle);
      }
      _isMoving = false;
      return;
    }

    // Prepara para o movimento suave
    moveStartTime = millis();
    moveDuration = duration;
    for (int i = 0; i < NUM_SERVOS; i++)
    {
      startAngles[i] = currentAngles[i]; // Inicia da posição interpolada ATUAL
      targetAngles[i] = constrain(newTargetAngles[i], minAngles[i], maxAngles[i]);
    }
    _isMoving = true;
  }

  /**
   * @brief Atualiza a posição dos servos com base no tempo decorrido.
   * Deve ser chamado na função loop() principal.
   */
  void update()
  { // <-- DEFINIÇÃO PARA O LINKER
    if (!_isMoving)
      return; // Economiza processamento se não estiver movendo

    unsigned long elapsedTime = millis() - moveStartTime;
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

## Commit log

2025-09-25 Adicionando banco de imagens na raiz do repo
2025-09-25 Teste de commit no vscode recem configurado
2025-09-25 Update componentes.md
    Adicionando campo de impactos do consumo de corrente dos servos motores.
2025-10-25 Update robotic_arm.cpp
    Adicionando:
    - Controle suave de PWM (default ou custom)
    - Função de ações concorrentes
    - Comentários
2025-10-25 Rename robotic_arm.cpp to [LEGACY]robotic_arm.cpp
    Alterando nome do arquivo original para servir de backtrack no futuro, pois esse código será refatorado para melhorar a leitura e debug posteriormente
2025-10-29 Adicionando novos arquivos
    Foram criados o sequencer e o macro manager para possibilitar o carregamento fluido das poses e, assim, criar uma sequência de movimentos pré definidos.
2025-10-29 Update CommandParser.cpp
    Implementando função para mover todos os servos ao mesmo tempo
2025-11-27 Implementação do ROS e fixes de performance
    [Calibration.cpp, CommandParser.cpp, Config.h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]
2025-11-27 Adicionado guia de utilização ROS e melhoria da documentação
2025-12-18 Port de ROS com script em python
2025-12-18 Ajuste de documentação geral
2025-12-18 Add initial project description for robotic arm
2025-12-18 Revise project structure and arm specifications
    Redefine project structure and update robotic arm details.
